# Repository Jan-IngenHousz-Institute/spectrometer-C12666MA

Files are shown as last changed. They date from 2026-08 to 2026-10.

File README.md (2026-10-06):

# C12666MA spectrometer

Hamamatsu C12666MA micro-spectrometer (340–780 nm, 256 pixels) read by a
Raspberry Pi Pico through an MCP3301 13-bit ADC, on the JII "C12666MA Board
v2". Includes a live GUI for chlorophyll fluorescence: two wavelength regions
(`incident_light`, `fluorescence`) and their ratio, the *rel. fluo. yield*,
plotted and recorded over time.

```
firmware/main.py      MicroPython firmware (copy to the Pico as main.py)
c12666ma/             Python package: driver, analysis, recorder, GUI
calibration/          pixel -> wavelength calibration and its source data
tools/hw_check.py     speed / reliability / noise check of a connected board
tests/                unit tests (no hardware needed)
notebooks/            the original measurement notebooks (K. Tolsma, 2026)
hardware/kicad/       PCB v2, two variants: Pico on the back / on the front
legacy/arduino/       earlier Arduino Uno sketches, incl. the MCP3301 bench test
```

## Quick start

```
pip install -r requirements.txt
python -m c12666ma            # the GUI
```

1. **Connect**, then **Start**. "As fast as possible" streams one spectrum per
   integration time (about 190 spectra/s at the 5.2 ms minimum). Otherwise
   set a period; the minimum is averages × integration time.
2. Cover the sensor or switch the light off and press **Take dark**. The
   yield needs a dark spectrum taken with the same gain, integration time and
   averages, and the GUI tells you when the current one no longer matches.
3. Drag the blue (`incident_light`) and red (`fluorescence`) regions, or type
   their limits.
4. Select **3D spectrum history** to view the most recent spectra as a surface
   over wavelength, time and counts. The view keeps up to 5000 spectra in
   memory, can show the latest 2–500, and updates while it is open.
5. **Start recording** writes one CSV per measurement.

### Rel. fluo. yield

`fluorescence / incident_light`, where each term is the sum of
dark-subtracted counts over its region. A region "has signal" when that sum
is more than *k* × its noise (k = 5 by default; the noise comes from the dark
frames).

| incident_light | fluorescence | result |
|---|---|---|
| signal | any | fluorescence / incident_light |
| no signal | signal | empty + warning *fluorescence without incident light* |
| no signal | no signal | 0 |

Frames with a pixel at saturation in either region are flagged (orange in
the plot, `;saturated` in the file). The saturation level is about 3100
counts at high gain and about 1950 at low gain; both can be adjusted in the
GUI.

### Recording format

Open a recording with `pandas.read_csv(path, comment="#")`. The header lines
(`# ...`) hold the settings, regions and calibration. The `kind` column
separates the row types:

- `wavelength_nm`: the wavelength of every pixel column `px0..px255`
- `dark` / `dark_std`: the dark reference (written whenever one is taken)
- `spectrum`: one row per spectrum, with the timestamp (start of
  integration), `t_s`, sequence number, settings, optionally
  `incident_light`, `fluorescence`, `rel_fluo_yield`, `yield_status`, and the
  raw counts (not dark-subtracted).

### Scripting

```python
from c12666ma import Spectrometer

with Spectrometer.open() as spec:          # finds the Pico automatically
    spec.set_integration_us(20_000)
    frame = spec.read_frame()              # frame.counts: 256 values
    spec.start_stream(period_us=0)
    frame = spec.frames.get()              # frames keep arriving until stop_stream()
    spec.stop_stream()
```

## Firmware

Copy `firmware/main.py` to the Pico as `main.py`, with Thonny or with
`mpremote cp firmware/main.py :main.py`. The serial protocol is documented
at the top of the file. Commands are text lines (`set_integration,20000`,
`spec,raw`, ...), and the v1 commands still work. Settings stay in RAM until
you send `save`.

The sensor clock (200 kHz), the start pulses and the ADC conversions are
generated by the Pico's PIO state machines, and DMA moves the samples to RAM.
The readout therefore doesn't depend on Python timing. Per the datasheet,
the integration time is the interval between start pulses, so it is exactly
N clocks for every pixel. Readout overlaps the next integration, so
streaming has no dead time.

Measured on the board in October 2026 (`python tools/hw_check.py`, 60 s
run):

| | |
|---|---|
| frame rate at the 5.175 ms minimum integration | 193.2 spectra/s, period exact to 1 µs |
| dropped frames / checksum errors / ADC framing errors | 0 / 0 / 0 (11 593 frames) |
| device CPU load at that rate | 48 % |
| dark noise | ~11 counts rms per pixel (old firmware: same median, but outliers up to 350) |

The noise floor (~11 mV rms) is set by the analog front end, not the sensor
(datasheet readout noise 0.5 mV).

## Wavelength calibration

There is no Hamamatsu inspection sheet for this unit, so
`calibration/fit_wavelength.py` fits a quadratic from two sources. The first
is four LED spectra measured with both this sensor and a reference
spectrometer (`calibration/LR1B/`). The second is the chlorophyll
fluorescence peaks (685 / ~737 nm) in 13 leaf recordings, which anchor the
red end beyond the last LED:

    nm = 345.98 + 2.3235·p − 0.0017379·p²     (p = pixel 0..255)

The RMS residual is 2.3 nm. Treat it as about ±3 nm between 470 and 745 nm,
and less certain outside that range. The coefficients are also stored on the
device (`get_wl_coeffs`), and the GUI uses them from there. Pixel → λ is
unchanged from the original firmware, so old data can use the same formula.

## Hardware notes (board v2)

- MCP3301 DOUT (5 V logic) is wired straight to GP16. The RP2040 is not 5 V
  tolerant. For the next revision, add a divider or a 3.3 V buffer; a
  ~2.2 kΩ series resistor is the quick fix.
- The video output reaches the ADC through 5 kΩ with no buffer amplifier (the
  datasheet recommends a CMOS op-amp buffer). This limits the ADC clock and
  probably adds noise.
- GP15 (the LED / excitation light) is not routed on the PCB and has to be
  wired separately.
- The schematic uses JII library symbols ("Library JII") that are embedded
  in the files but not included as a library.

## Development

```
python -m pytest                       # unit tests
python tools/hw_check.py               # with a board connected
python calibration/fit_wavelength.py   # re-fit the calibration
```

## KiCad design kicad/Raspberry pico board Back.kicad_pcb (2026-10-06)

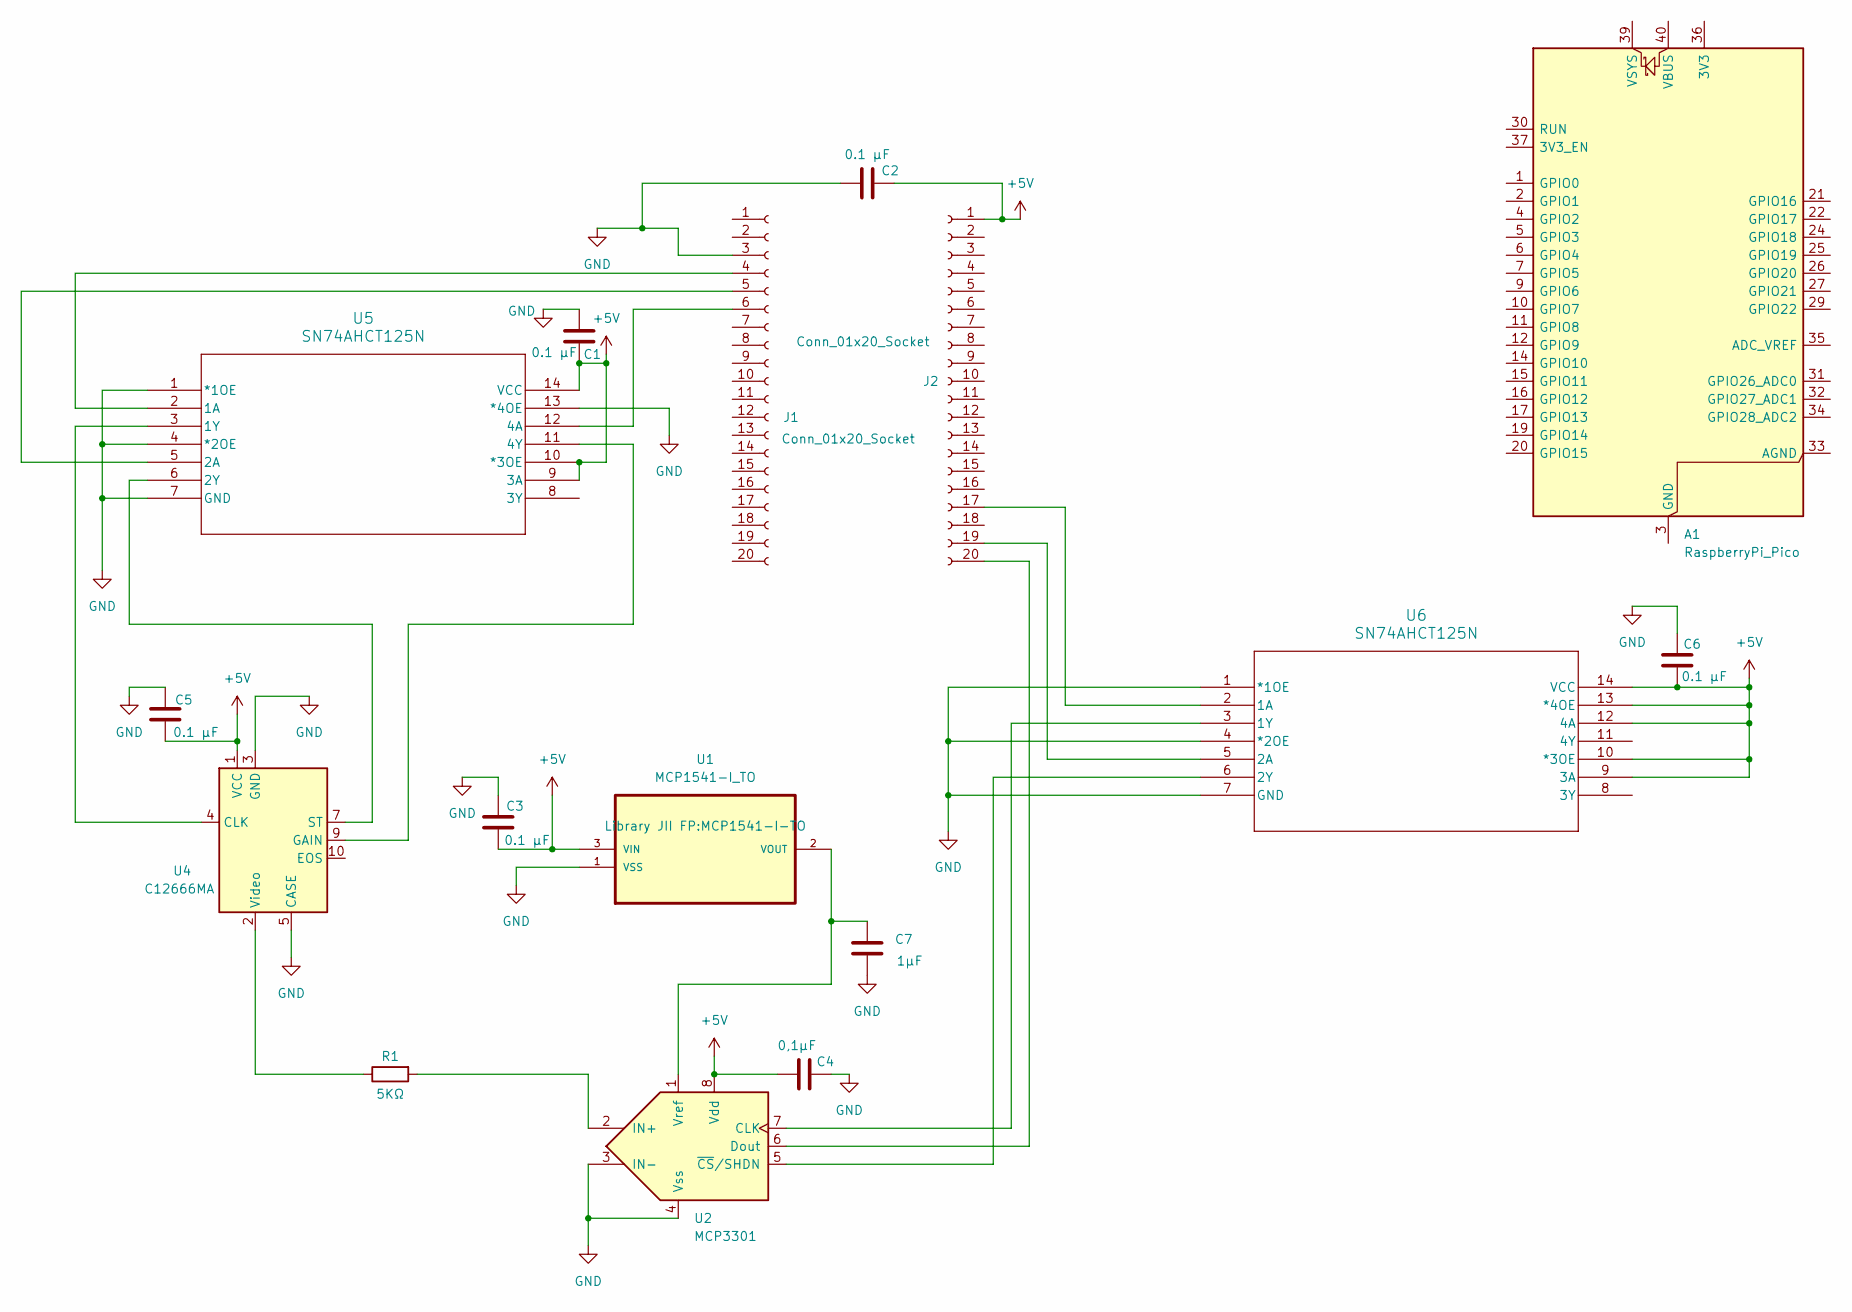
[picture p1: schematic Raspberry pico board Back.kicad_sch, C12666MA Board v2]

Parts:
A1: RaspberryPi_Pico; RaspberryPi_Pico_Common_Unspecified
C1, C2, C3, C5, C6: 0.1 μF; C_0805_2012Metric_Pad1.18x1.45mm_HandSolder
C4: 0,1μF; C_0805_2012Metric_Pad1.18x1.45mm_HandSolder
C7: 1μF; C_0805_2012Metric_Pad1.18x1.45mm_HandSolder
J1, J2: Conn_01x20_Socket; PinHeader_1x20_P2.54mm_Vertical
R1: 5KΩ; R_0805_2012Metric_Pad1.20x1.40mm_HandSolder
U1: MCP1541-I_TO; MCP1541-I-TO; MPN MCP1541-I/TO
U2: MCP3301; MCP3301_BI_P
U4: C12666MA; Hamamatsu_C12880
U5, U6: SN74AHCT125N

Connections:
+5V: C1.2, C2.2, C3.2, C4.1, C5.2, C6.2, J2.1, U1.3 (VIN), U2.8 (Vdd), U4.1 (VCC), U5.9 (3A), U5.10 (*3OE), U5.14 (VCC), U6.9 (3A), U6.10 (*3OE), U6.12 (4A), U6.13 (*4OE), U6.14 (VCC)
GND: C1.1, C2.1, C3.1, C4.2, C5.1, C6.1, C7.2, J1.3, U1.1 (VSS), U2.3 (IN-), U2.4 (Vss), U4.3 (GND), U4.5 (CASE), U5.1 (*1OE), U5.4 (*2OE), U5.7 (GND), U5.13 (*4OE), U6.1 (*1OE), U6.4 (*2OE), U6.7 (GND)
unnamed: A1.3 (GND), A1.8 (GND), A1.13 (GND), A1.18 (GND), A1.23 (GND), A1.28 (GND), A1.38 (GND)
unnamed: J1.4, U5.2 (1A)
unnamed: J1.5, U5.5 (2A)
unnamed: J1.6, U5.12 (4A)
unnamed: J2.17, U6.2 (1A)
unnamed: J2.19, U6.5 (2A)
unnamed: J2.20, U2.6 (Dout)
unnamed: C7.1, U1.2 (VOUT), U2.1 (Vref)
unnamed: U2.7 (CLK), U6.3 (1Y)
unnamed: R1.2, U2.2 (IN+)
unnamed: U2.5 (~CS/SHDN), U6.6 (2Y)
unnamed: U4.4 (CLK), U5.3 (1Y)
unnamed: U4.9 (GAIN), U5.11 (4Y)
unnamed: U4.7 (ST), U5.6 (2Y)
unnamed: R1.1, U4.2 (Video)

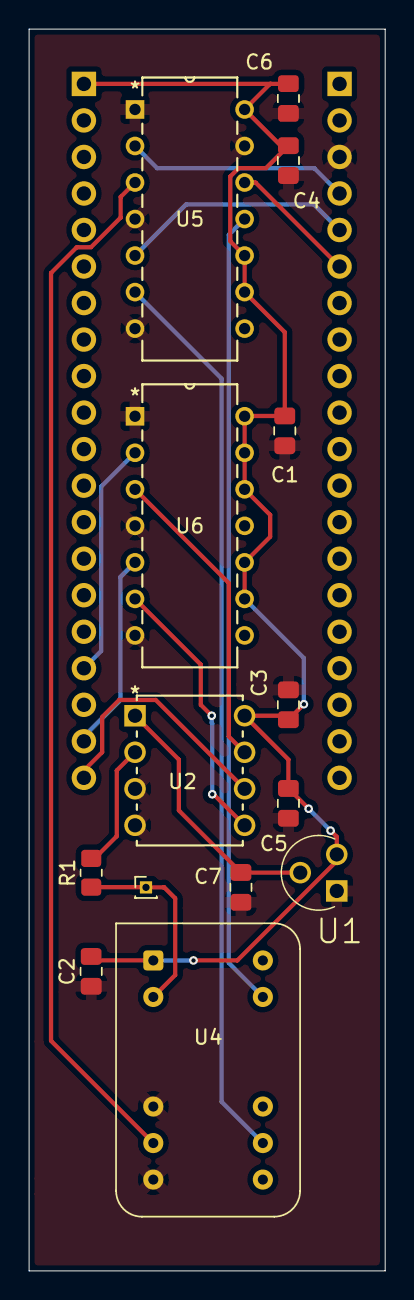
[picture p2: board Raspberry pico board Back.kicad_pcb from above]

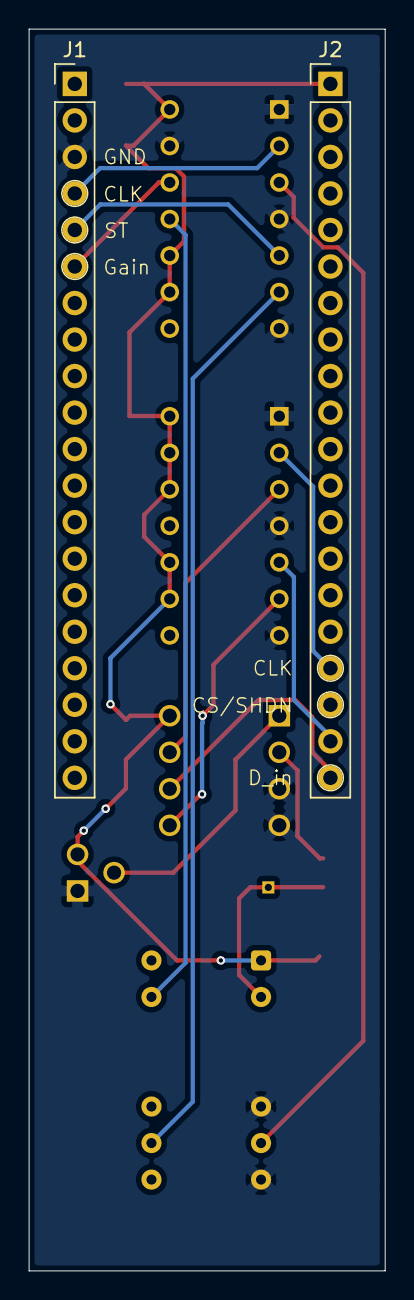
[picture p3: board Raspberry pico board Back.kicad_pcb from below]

Board: 2 copper layers, 24.8 x 86.4 mm, 15 parts (2 on the bottom side), 16 nets.

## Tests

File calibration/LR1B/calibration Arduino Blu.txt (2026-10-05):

296.156 13.772
296.345 82.772
296.534 21.772
296.723 29.772
296.912 33.772
297.101 27.772
297.290 11.772
297.479 13.772
297.668 39.771
297.858 -14.229
298.047 65.771
298.236 62.771
298.425 120.771
298.614 54.771
298.803 90.771
298.992 62.771
299.181 47.771
299.370 36.770
299.559 18.770
299.748 -8.230
299.937 29.770
300.126 62.770
300.315 9.770
300.504 35.770
300.693 66.770
300.882 41.769
301.071 -14.231
301.260 29.769
301.449 45.769
301.638 58.769
301.827 -9.231
302.016 43.769
302.205 81.769
302.395 63.768
302.584 48.768
302.773 17.768
302.962 66.768
303.151 75.768
303.340 56.768
303.529 31.768
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

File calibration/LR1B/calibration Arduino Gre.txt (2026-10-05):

296.156 6.886
296.345 34.886
296.534 39.886
296.723 76.886
296.912 33.886
297.101 -80.114
297.290 -17.114
297.479 49.886
297.668 31.886
297.858 29.886
298.047 34.886
298.236 9.886
298.425 49.885
298.614 65.885
298.803 85.885
298.992 39.885
299.181 -15.115
299.370 54.885
299.559 77.885
299.748 51.885
299.937 42.885
300.126 74.885
300.315 44.885
300.504 37.885
300.693 43.885
300.882 24.885
301.071 -12.115
301.260 45.885
301.449 85.885
301.638 60.884
301.827 41.884
302.016 71.884
302.205 62.884
302.395 41.884
302.584 -11.116
302.773 42.884
302.962 58.884
303.151 12.884
303.340 54.884
303.529 51.884
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

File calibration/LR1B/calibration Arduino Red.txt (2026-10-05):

296.156 42.986
296.345 81.986
296.534 42.986
296.723 30.986
296.912 2.986
297.101 35.986
297.290 -2.014
297.479 22.986
297.668 51.986
297.858 92.986
298.047 -22.014
298.236 -22.014
298.425 -5.014
298.614 59.986
298.803 -7.014
298.992 5.986
299.181 -65.014
299.370 -37.014
299.559 15.986
299.748 11.986
299.937 14.986
300.126 -3.014
300.315 59.986
300.504 23.986
300.693 5.986
300.882 41.986
301.071 43.986
301.260 -19.014
301.449 6.986
301.638 56.986
301.827 43.986
302.016 16.986
302.205 -21.014
302.395 -1.014
302.584 13.986
302.773 -3.014
302.962 45.986
303.151 22.985
303.340 -0.015
303.529 22.985
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

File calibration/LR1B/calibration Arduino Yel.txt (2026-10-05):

296.156 -18.171
296.345 -27.171
296.534 6.829
296.723 50.829
296.912 20.829
297.101 27.829
297.290 51.829
297.479 25.829
297.668 74.829
297.858 68.829
298.047 65.828
298.236 49.828
298.425 34.828
298.614 36.828
298.803 79.828
298.992 33.828
299.181 23.828
299.370 15.828
299.559 18.828
299.748 42.828
299.937 -2.172
300.126 -36.173
300.315 15.827
300.504 13.827
300.693 88.827
300.882 12.827
301.071 57.827
301.260 71.827
301.449 35.827
301.638 18.827
301.827 3.827
302.016 45.827
302.205 34.826
302.395 83.826
302.584 -2.174
302.773 -8.174
302.962 -5.174
303.151 35.826
303.340 52.826
303.529 43.826
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

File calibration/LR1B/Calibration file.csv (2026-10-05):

timestamp | pixel0 | 1 | 2 | 3 | 4 | 5 | 6 | 7 | 8 | 9 | 10 | 11 | 12 | 13 | 14 | 15 | 16 | 17 | 18 | 19 | 20 | 21 | 22 | 23 | 24 | 25 | 26 | 27 | 28 | 29 | 30 | 31 | 32 | 33 | 34 | 35 | 36 | 37 | 38 | 39 | 40 | 41 | 42 | 43 | 44 | 45 | 46 | 47 | 48 | 49 | 50 | 51 | 52 | 53 | 54 | 55 | 56 | 57 | 58
7-8-2026 10:11 | 17 | 31 | 32 | 24 | 22 | 37 | 30 | 6 | 17 | 28 | 24 | 22 | 20 | 23 | 23 | 24 | 17 | 20 | 22 | 28 | 20 | 20 | 29 | 26 | 24 | 28 | 34 | 17 | 24 | 26 | 20 | 25 | 18 | 26 | 25 | 28 | 23 | 33 | 41 | 53 | 62 | 77 | 99 | 108 | 148 | 168 | 222 | 294 | 372 | 474 | 610 | 765 | 918 | 1056 | 1154 | 1140 | 1070 | 961 | 853
7-8-2026 10:11 | 24 | 27 | 27 | 23 | 23 | 33 | 34 | 27 | 22 | 31 | 39 | 22 | 23 | 36 | 29 | 26 | 31 | 34 | 22 | 32 | 28 | 26 | 45 | 36 | 35 | 32 | 29 | 26 | 27 | 31 | 27 | 26 | 23 | 27 | 35 | 37 | 33 | 43 | 49 | 49 | 67 | 92 | 96 | 125 | 148 | 178 | 226 | 292 | 382 | 476 | 621 | 775 | 924 | 1068 | 1149 | 1153 | 1072 | 972 | 856
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

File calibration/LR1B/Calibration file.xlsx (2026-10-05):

timestamp | pixel0 | 1 | 2 | 3 | 4 | 5 | 6 | 7 | 8 | 9 | 10 | 11 | 12 | 13 | 14 | 15 | 16 | 17 | 18 | 19 | 20 | 21 | 22 | 23 | 24 | 25 | 26 | 27 | 28 | 29 | 30 | 31 | 32 | 33 | 34 | 35 | 36 | 37 | 38 | 39 | 40 | 41 | 42 | 43 | 44 | 45 | 46 | 47 | 48 | 49 | 50 | 51 | 52 | 53 | 54 | 55 | 56 | 57 | 58
2026-08-07 10:11 | 17 | 31 | 32 | 24 | 22 | 37 | 30 | 6 | 17 | 28 | 24 | 22 | 20 | 23 | 23 | 24 | 17 | 20 | 22 | 28 | 20 | 20 | 29 | 26 | 24 | 28 | 34 | 17 | 24 | 26 | 20 | 25 | 18 | 26 | 25 | 28 | 23 | 33 | 41 | 53 | 62 | 77 | 99 | 108 | 148 | 168 | 222 | 294 | 372 | 474 | 610 | 765 | 918 | 1056 | 1154 | 1140 | 1070 | 961 | 853
2026-08-07 10:11 | 24 | 27 | 27 | 23 | 23 | 33 | 34 | 27 | 22 | 31 | 39 | 22 | 23 | 36 | 29 | 26 | 31 | 34 | 22 | 32 | 28 | 26 | 45 | 36 | 35 | 32 | 29 | 26 | 27 | 31 | 27 | 26 | 23 | 27 | 35 | 37 | 33 | 43 | 49 | 49 | 67 | 92 | 96 | 125 | 148 | 178 | 226 | 292 | 382 | 476 | 621 | 775 | 924 | 1068 | 1149 | 1153 | 1072 | 972 | 856
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

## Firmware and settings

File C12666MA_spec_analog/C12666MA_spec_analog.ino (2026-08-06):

/*
 * ============================================================================
 *  C12666MA_spectrometer.ino
 *  Hamamatsu C12666MA micro-spectrometer reader for the Arduino Uno (ATmega328P)
 * ============================================================================
 *
 *  Reads all 256 pixels of the sensor and sends them to a host PC over USB
 *  serial, using simple comma-separated text commands. Beginner-friendly:
 *  plain functions and global variables, one file, lots of comments.
 *
 *  --- WIRING (Uno is 5V, so no level shifters or op-amps are required) -------
 *     Sensor CLK   -> Uno A2   (digital output)
 *     Sensor ST    -> Uno A1   (digital output)
 *     Sensor VIDEO -> Uno A3   (ANALOG input, read with analogRead)
 *     Sensor Gain  -> Uno A0   (digital output - see GAIN PIN note below)
 *     Sensor +Vs   -> Uno 5V
 *     Sensor GND   -> Uno GND
 *     Sensor EOS   -> not used by this sketch, can be left unconnected
 *     Sensor Case  -> Uno GND (recommended, reduces noise pickup)
 *
 *  --- GAIN PIN NOTE -----------------------------------------------------------
 *     Unlike the C12880MA, the C12666MA has a Gain pin (sensor pin 9) instead
 *     of a Trigger pin. Per the Hamamatsu datasheet:
 *       - Low gain:  pin left open, or driven/pulled to Vdd (5V)
 *       - High gain: pin driven to GND (<0.4V)
 *     The sensor already has a 10 kOhm internal pull-up to Vdd on this pin, so
 *     do NOT add an external pull-up or pull-down resistor - just wire it
 *     straight to A0. This sketch drives A0 as an output so gain is set
 *     explicitly in software rather than left floating.
 *
 *  --- INTEGRATION TIME NOTE ----------------------------------------------------
 *     The C12666MA's datasheet-specified minimum integration time is much
 *     longer than the C12880MA's (roughly 1.28 ms vs ~11 us). This sketch
 *     defaults to and enforces a 1280 us floor - see MIN_INTEGRATION_US below.
 *
 *  --- ACQUISITION PROTOCOL (verified against groupgets/c12666ma) -------------
 *     The C12666MA's readout sequence is NOT the same shape as the C12880MA's
 *     and differs in two important ways:
 *       1. VIDEO only updates once every 4 CLK pulses (the datasheet states
 *          "video output is 1/4 of the clock pulse frequency"), so each
 *          pixel needs a 4-clock group, with the valid sample taken on the
 *          first clock's falling edge.
 *       2. ST idles HIGH and is only pulsed briefly LOW - once to mark the
 *          start of integration, once to mark the end - rather than staying
 *          low for the whole pixel readout. The datasheet notes: "The clock
 *          pulse should be set from high to low just once when the start
 *          pulse is low. The internal shift register starts operating at
 *          this timing," i.e. that single edge is what actually triggers
 *          the sensor, so it has to be timed precisely.
 *     This sketch's acquireOnePass() follows that six-step sequence (leading
 *     clocks, start pulse, integration, stop pulse, 4-clocks-per-pixel read,
 *     trailing clocks), matching the reference sketch at:
 *       https://github.com/groupgets/c12666ma
 *       https://github.com/tricorderproject/arducordermini
 *
 *  --- HOW TO USE -------------------------------------------------------------
 *     1. Upload with the Arduino IDE (board: "Arduino Uno").
 *     2. Open Serial Monitor at 115200 baud, line ending = "Carriage Return".
 *     3. Type commands (see the table in handleCommand() below), e.g.:
 *          hello
 *          set_integration,2000
 *          set_gain,1      (0 = low gain, 1 = high gain)
 *          dark            (capture a dark reference with the sensor covered)
 *          spec            (dark-subtracted spectrum, 256 numbers)
 *          spec,raw        (raw spectrum, 256 numbers)
 *
 *  Adapted from a C12880MA sketch ported from the GroupGets C12880MA Arduino
 *  example (https://github.com/groupgets/c12666ma) for the C12666MA sensor.
 *  Timing constants that are sensor-specific have been called out above -
 *  please verify them against your hardware before trusting the output.
 * ============================================================================
 */

#include <EEPROM.h>

// ============================================================================
//  1. PINS & CONSTANTS
// ============================================================================

// Pin assignments (match the GroupGets breakout layout).
const uint8_t SPEC_CLK   = A2;   // clock output to the sensor
const uint8_t SPEC_ST    = A1;   // start pulse output to the sensor
const uint8_t SPEC_VIDEO = A3;   // analog video input from the sensor
const uint8_t SPEC_GAIN  = A0;   // gain select output to the sensor (pin 9)
const uint8_t LED_PIN    = 2;    // external status LED (pin 0/1 are used by
                                  // Serial - don't repurpose those)

// Gain pin logic levels (see GAIN PIN note above).
const uint8_t GAIN_LOW  = HIGH;  // low gain:  pin at/near Vdd
const uint8_t GAIN_HIGH = LOW;   // high gain: pin at/near GND

// The sensor has 256 pixels (spectral channels).
const int SPEC_CHANNELS = 256;

// Half-period of each clock pulse, in microseconds. 1 us gives a clean,
// slow clock that the sensor is happy with. Bigger = slower and safer.
// The C12666MA datasheet allows a clock frequency of 1 kHz to 800 kHz
// (f(CLK)), so this slow default clock is comfortably within range.
const int CLK_DELAY_US = 1;

// Datasheet-specified minimum integration time for the C12666MA is about
// 1.28 ms. We enforce this floor in set_integration() so a mistaken
// set_integration,0 command can't silently produce underexposed frames.
const unsigned long MIN_INTEGRATION_US = 5000UL;

// Averaging is capped so the uint16 accumulator (in g_data) cannot overflow:
// 63 * 1023 = 64449, which is below 65535. This also keeps us inside the
// Uno's 2 KB of RAM (a 32-bit accumulator array would not fit next to g_dark).
const uint8_t MAX_AVG = 63;

// ============================================================================
//  2. CONFIGURATION STORED IN EEPROM
// ============================================================================
// The Uno has no filesystem, so settings that must survive a power cycle are
// kept in EEPROM. A "magic" byte lets us detect a blank chip and load defaults.

const uint8_t CONFIG_MAGIC = 0x66;   // bumped from the C12880MA version (0x43)
                                      // since the struct below gained a field -
                                      // change this again if you change the struct

struct Config {
  uint8_t       magic;             // must equal CONFIG_MAGIC if valid
  char          name[16];          // human-friendly device name
  unsigned long integration_us;    // extra exposure time (microseconds)
  uint8_t       n_avg;             // number of frames to average (1..MAX_AVG)
  float         wl_coeffs[6];      // wavelength polynomial A0..A5 (used host-side)
  uint8_t       high_gain;         // 0 = low gain, 1 = high gain
};

Config g_cfg;   // the live copy of our settings

// ============================================================================
//  3. FRAME BUFFERS  (the biggest users of RAM)
// ============================================================================

uint16_t g_data[SPEC_CHANNELS];   // latest frame; also used as the average sum
uint16_t g_dark[SPEC_CHANNELS];   // dark reference frame
bool     g_have_dark = false;     // true once a dark frame has been captured
bool     g_led_on = false;        // current LED state (not persisted in EEPROM -
                                   // always starts off after a reboot)

// ============================================================================
//  4. SERIAL COMMAND BUFFER
// ============================================================================
// We read characters into a fixed char array (not a String) to avoid the
// memory-fragmentation problems that String can cause on small AVR chips.

char    g_cmd[40];
uint8_t g_cmd_len = 0;

// ---------------------------------------------------------------------------
//  Soft reset: jumping to address 0 restarts the sketch. (Simple, not a full
//  hardware reset, but fine for the "reboot" command.)
// ---------------------------------------------------------------------------
void (*resetBoard)(void) = 0;

// ============================================================================
//  EEPROM helpers
// ============================================================================

void saveConfig() {
  EEPROM.put(0, g_cfg);
}

void loadConfig() {
  EEPROM.get(0, g_cfg);
  if (g_cfg.magic != CONFIG_MAGIC) {
    // Blank or outdated EEPROM: fill in sensible defaults and store them.
    g_cfg.magic = CONFIG_MAGIC;
    strcpy(g_cfg.name, "C12666MA");
    g_cfg.integration_us = MIN_INTEGRATION_US;   // datasheet minimum, not 0
    g_cfg.n_avg = 1;               // no averaging by default
    for (int i = 0; i < 6; i++) g_cfg.wl_coeffs[i] = 0.0;
    g_cfg.high_gain = 0;           // low gain by default
    saveConfig();
  }
  // Make sure a corrupted value can never break averaging or integration.
  if (g_cfg.n_avg < 1)       g_cfg.n_avg = 1;
  if (g_cfg.n_avg > MAX_AVG) g_cfg.n_avg = MAX_AVG;
  if (g_cfg.integration_us < MIN_INTEGRATION_US) g_cfg.integration_us = MIN_INTEGRATION_US;
}

// ============================================================================
//  5. ACQUISITION
// ============================================================================

// One low/high clock pulse on SPEC_CLK (order matches the reference sketch;
// what matters for a free-running train is that transitions are evenly
// spaced, so this is equivalent to a high/low pulse for anything except the
// edge-critical start/stop pulses handled separately in pulseStartStop()).
void pulseClock() {
  digitalWrite(SPEC_CLK, LOW);
  delayMicroseconds(CLK_DELAY_US);
  digitalWrite(SPEC_CLK, HIGH);
  delayMicroseconds(CLK_DELAY_US);
}

// Push the current gain setting out to the sensor's Gain pin.
void applyGain() {
  digitalWrite(SPEC_GAIN, g_cfg.high_gain ? GAIN_HIGH : GAIN_LOW);
}

// A brief ST HIGH->LOW->HIGH pulse, timed to CLK edges. Called once to mark
// the start of integration and again to mark the end - the sequence is
// identical both times (see ACQUISITION PROTOCOL note up top). The single
// CLK falling edge that happens while ST is LOW is what actually triggers
// the sensor's internal shift register, per the datasheet.
void pulseStartStop() {
  digitalWrite(SPEC_CLK, LOW);
  delayMicroseconds(CLK_DELAY_US);
  digitalWrite(SPEC_CLK, HIGH);
  digitalWrite(SPEC_ST, LOW);
  delayMicroseconds(CLK_DELAY_US);

  digitalWrite(SPEC_CLK, LOW);
  delayMicroseconds(CLK_DELAY_US);
  digitalWrite(SPEC_CLK, HIGH);
  digitalWrite(SPEC_ST, HIGH);
  delayMicroseconds(CLK_DELAY_US);
}

// Run the sensor once and ADD the 256 readings into g_data (so it can be
// called several times in a row to average). Six-step sequence verified
// against the groupgets/c12666ma reference sketch - see ACQUISITION
// PROTOCOL note up top for why this differs from a typical C12880MA sketch.
void acquireOnePass() {
  // -- Step 1: one full frame's worth of leading clocks, ST idling HIGH. --
  for (int i = 0; i < SPEC_CHANNELS; i++) pulseClock();

  // -- Step 2: start pulse - marks the beginning of integration. --
  pulseStartStop();

  // -- Step 3: integration window. ST stays HIGH; CLK keeps running so the
  //    sensor's internal clocking stays alive, in groups of 2 pulseClock()
  //    calls (~1 clock cycle each). We time this against a real elapsed-
  //    microsecond count via micros(), NOT by estimating clock counts -
  //    digitalWrite() call overhead on the Uno is several microseconds per
  //    call, which dwarfs CLK_DELAY_US and made a clock-counting estimate
  //    badly inaccurate. This loop instead keeps pulsing until the
  //    requested integration_us has actually elapsed. --
  unsigned long intStart = micros();
  while ((unsigned long)(micros() - intStart) < g_cfg.integration_us) {
    pulseClock();
    pulseClock();
  }

  // -- Step 4: stop pulse - marks the end of integration; pixel shift-out
  //    begins right after. --
  pulseStartStop();

  // -- Step 5: read the 256 real pixels. Each pixel gets a 4-clock group;
  //    VIDEO is valid on the first clock's falling edge, so that's where we
  //    sample. The remaining 3 clocks just shift to the next pixel. --
  for (int i = 0; i < SPEC_CHANNELS; i++) {
    digitalWrite(SPEC_CLK, LOW);
    delayMicroseconds(CLK_DELAY_US);
    digitalWrite(SPEC_CLK, HIGH);
    delayMicroseconds(CLK_DELAY_US);
    digitalWrite(SPEC_CLK, LOW);
    // Settling delay before sampling. If a buffer op-amp is in the signal
    // path, this needs to cover its worst-case slew time, not just RC
    // settling: e.g. the OPA347's slew rate is only ~0.17 V/us typical, so
    // a full-scale step (a few volts, as can happen pixel-to-pixel at a
    // sharp spectral edge) can take ~15-20us to fully settle. Without a
    // buffer, a much shorter delay (a few us) is enough for the sensor's
    // own ~150 ohm output impedance to settle. Tune this to your actual
    // signal path; too short truncates real amplitude (readings looking
    // "compressed" versus the scope), too long just slows readout.
    delayMicroseconds(20);
    g_data[i] += analogRead(SPEC_VIDEO);   // valid right after this falling edge
    digitalWrite(SPEC_CLK, HIGH);
    delayMicroseconds(CLK_DELAY_US);
    pulseClock();
    pulseClock();
  }

  // -- Step 6: one full frame's worth of trailing clocks, leaves the sensor
  //    ready for the next acquisition. --
  for (int i = 0; i < SPEC_CHANNELS; i++) pulseClock();
}

// Read a full spectrum into g_data, averaging g_cfg.n_avg passes.
void readSpectrometer() {
  for (int i = 0; i < SPEC_CHANNELS; i++) g_data[i] = 0;   // clear accumulator

  for (uint8_t p = 0; p < g_cfg.n_avg; p++) acquireOnePass();

  if (g_cfg.n_avg > 1) {
    for (int i = 0; i < SPEC_CHANNELS; i++) g_data[i] /= g_cfg.n_avg;
  }
}

// Capture the current reading as the dark reference.
void captureDark() {
  readSpectrometer();
  for (int i = 0; i < SPEC_CHANNELS; i++) g_dark[i] = g_data[i];
  g_have_dark = true;
}

// ============================================================================
//  6. OUTPUT HELPERS
// ============================================================================

// Print the spectrum as one line of comma-separated numbers, ending in '\r'.
// raw == true  -> raw counts
// raw == false -> dark-subtracted counts (clamped at 0), if a dark frame exists
void printSpectrum(bool raw) {
  for (int i = 0; i < SPEC_CHANNELS; i++) {
    int value;
    if (raw || !g_have_dark) {
      value = g_data[i];
    } else {
      value = (int)g_data[i] - (int)g_dark[i];
      if (value < 0) value = 0;
    }
    Serial.print(value);
    if (i < SPEC_CHANNELS - 1) Serial.print(',');
  }
  Serial.print('\r');
}

// Print the six wavelength coefficients as a JSON array.
void printWlCoeffs() {
  Serial.print(F("{\"wl_coeffs\":["));
  for (int i = 0; i < 6; i++) {
    Serial.print(g_cfg.wl_coeffs[i], 8);   // 8 decimal places
    if (i < 5) Serial.print(',');
  }
  Serial.print(F("]}\r"));
}

// ============================================================================
//  7. COMMAND HANDLING
// ============================================================================
//
//  Supported commands (each line ends with Carriage Return, '\r'):
//    hello                     -> "C12666MA,v1.0"        (auto-discovery)
//    idn                       -> "C12666MA_UNO_v1.0"
//    spec                      -> dark-subtracted spectrum (256 numbers)
//    spec,raw                  -> raw spectrum (256 numbers)
//    set_integration,<us>      -> {"integration_us":<n>}  (floored at 1280)
//    get_integration           -> <n>
//    set_gain,<0|1>            -> {"high_gain":<0|1>}     (0=low, 1=high)
//    get_gain                  -> <0|1>
//    set_led,<0|1>             -> {"led":<0|1>}          (0=off, 1=on)
//    get_led                   -> <0|1>
//    dark                      -> {"dark":"ok"}          (capture dark frame)
//    clear_dark                -> {"dark":"cleared"}
//    set_avg,<n>               -> {"n_avg":<n>}          (1..63)
//    get_avg                   -> <n>
//    set_wl_coeff,<i>,<value>  -> {"wl_coeffs":[...]}    (i = 0..5)
//    get_wl_coeffs             -> {"wl_coeffs":[...]}
//    set_name,<text>           -> {"device_name":"..."}
//    get_name                  -> <name>
//    reboot                    -> soft reset
//
void handleCommand(char *cmd) {
  // strtok() splits the command on commas. The first token is the command name.
  char *tok = strtok(cmd, ",");
  if (tok == NULL) return;

  if (strcmp(tok, "hello") == 0) {
    Serial.print(F("C12666MA,v1.0\r\n"));

  } else if (strcmp(tok, "idn") == 0) {
    Serial.print(F("C12666MA_UNO_v1.0\r\n"));

  } else if (strcmp(tok, "spec") == 0) {
    char *arg = strtok(NULL, ",");                 // optional "raw"
    bool raw = (arg != NULL && strcmp(arg, "raw") == 0);
    readSpectrometer();
    printSpectrum(raw);
    Serial.print("\r\n");

  } else if (strcmp(tok, "set_integration") == 0) {
    char *arg = strtok(NULL, ",");
    if (arg != NULL) {
      unsigned long requested = atol(arg);
      g_cfg.integration_us = (requested < MIN_INTEGRATION_US) ? MIN_INTEGRATION_US : requested;
      saveConfig();
    }
    Serial.print(F("{\"integration_us\":"));
    Serial.print(g_cfg.integration_us);
    Serial.print(F("}\r\n"));

  } else if (strcmp(tok, "get_integration") == 0) {
    Serial.print(g_cfg.integration_us);
    Serial.print('\r');
    Serial.print("\n");

  } else if (strcmp(tok, "set_gain") == 0) {
    char *arg = strtok(NULL, ",");
    if (arg != NULL) {
      g_cfg.high_gain = (atoi(arg) != 0) ? 1 : 0;
      applyGain();
      saveConfig();
    }
    Serial.print(F("{\"high_gain\":"));
    Serial.print(g_cfg.high_gain);
    Serial.print(F("}\r\n"));

  } else if (strcmp(tok, "get_gain") == 0) {
    Serial.print(g_cfg.high_gain);
    Serial.print(F("\r\n"));

  } else if (strcmp(tok, "set_led") == 0) {
    char *arg = strtok(NULL, ",");
    if (arg != NULL) {
      g_led_on = (atoi(arg) != 0);
      digitalWrite(LED_PIN, g_led_on ? HIGH : LOW);
    }
    Serial.print(F("{\"led\":"));
    Serial.print(g_led_on);
    Serial.print(F("}\r\n"));

  } else if (strcmp(tok, "get_led") == 0) {
    Serial.print(g_led_on);
    Serial.print(F("\r\n"));

  } else if (strcmp(tok, "dark") == 0) {
    captureDark();
    Serial.print(F("{\"dark\":\"ok\"}\r\n"));

  } else if (strcmp(tok, "clear_dark") == 0) {
    g_have_dark = false;
    Serial.print(F("{\"dark\":\"cleared\"}\r\n"));

  } else if (strcmp(tok, "set_avg") == 0) {
    char *arg = strtok(NULL, ",");
    if (arg != NULL) {
      int n = atoi(arg);
      if (n < 1) n = 1;
      if (n > MAX_AVG) n = MAX_AVG;
      g_cfg.n_avg = (uint8_t)n;
      saveConfig();
    }
    Serial.print(F("{\"n_avg\":"));
    Serial.print(g_cfg.n_avg);
    Serial.print(F("}\r\n"));

  } else if (strcmp(tok, "get_avg") == 0) {
    Serial.print(g_cfg.n_avg);
    Serial.print(F("\r\n"));

  } else if (strcmp(tok, "set_wl_coeff") == 0) {
    char *sIndex = strtok(NULL, ",");
    char *sValue = strtok(NULL, ",");
    if (sIndex != NULL && sValue != NULL) {
      int idx = atoi(sIndex);
      if (idx >= 0 && idx < 6) {
        g_cfg.wl_coeffs[idx] = atof(sValue);       // text -> float
        saveConfig();
      }
    }
    printWlCoeffs();

  } else if (strcmp(tok, "get_wl_coeffs") == 0) {
    printWlCoeffs();

  } else if (strcmp(tok, "set_name") == 0) {
    char *arg = strtok(NULL, ",");
    if (arg != NULL) {
      strncpy(g_cfg.name, arg, sizeof(g_cfg.name) - 1);
      g_cfg.name[sizeof(g_cfg.name) - 1] = '\0';   // always null-terminate
      saveConfig();
    }
    Serial.print(F("{\"device_name\":\""));
    Serial.print(g_cfg.name);
    Serial.print(F("\"}\r\n"));

  } else if (strcmp(tok, "get_name") == 0) {
    Serial.print(g_cfg.name);
    Serial.print(F("\r\n"));

  } else if (strcmp(tok, "reboot") == 0) {
    Serial.print(F("{\"reboot\":\"ok\"}\r"));
    delay(50);            // let the reply flush out
    resetBoard();

  } else {
    Serial.print(F("{\"error\":\"unknown\"}\r\n"));
  }
}

// ============================================================================
//  8. setup() / loop()
// ============================================================================

void setup() {
  pinMode(SPEC_CLK,  OUTPUT);
  pinMode(SPEC_ST,   OUTPUT);
  pinMode(SPEC_GAIN, OUTPUT);
  pinMode(LED_PIN,   OUTPUT);
  digitalWrite(SPEC_CLK, LOW);
  digitalWrite(SPEC_ST,  HIGH);   // ST idles HIGH on the C12666MA, not LOW
  digitalWrite(LED_PIN,  LOW);    // start with the LED off
  // SPEC_VIDEO is an analog input and needs no pinMode().

  analogReference(DEFAULT);   // 5 V ADC reference (matches the VIDEO range)

  Serial.begin(115200);
  loadConfig();
  applyGain();   // drive the Gain pin to match the loaded/default setting
}

void loop() {
  // Collect characters until we see a line terminator, then run the command.
  while (Serial.available() > 0) {
    char c = Serial.read();

    if (c == '\r' || c == '\n') {
      if (g_cmd_len > 0) {
        g_cmd[g_cmd_len] = '\0';   // finish the string
        handleCommand(g_cmd);
        g_cmd_len = 0;
      }
    } else if (g_cmd_len < sizeof(g_cmd) - 1) {
      g_cmd[g_cmd_len++] = c;
    }
    // (characters beyond the buffer size are dropped on purpose)
  }
}

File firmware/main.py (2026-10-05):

# =============================================================================
#  main.py  -  Hamamatsu C12666MA spectrometer firmware
#  MicroPython for the Raspberry Pi Pico (RP2040) on the JII "C12666MA Board v2"
#  (C12666MA + MCP3301 13-bit ADC + MCP1541 4.096 V reference).
# =============================================================================
#
#  Install: copy this file to the Pico as  main.py  (Thonny: File > Save as >
#  Raspberry Pi Pico, or `mpremote cp firmware/main.py :main.py`). It starts on
#  power-up. Ctrl-C in Thonny still stops it and gives you the REPL.
#
#  --- WIRING (GPIO numbers) -----------------------------------------------------
#     GP2  sensor CLK      (via 74AHCT125 to 5 V)
#     GP3  sensor ST       (via 74AHCT125 to 5 V)
#     GP4  sensor Gain     (via 74AHCT125, 0 = high gain, 1 = low gain)
#     GP15 LED / excitation light
#     GP16 MCP3301 DOUT    (NOTE: 5 V logic straight into the Pico on board v2)
#     GP17 MCP3301 CS
#     GP18 MCP3301 CLK
#
#  --- HOW THE READOUT WORKS ------------------------------------------------------
#  All sensor timing is generated in hardware, so it does not depend on the
#  Python interpreter, garbage collection or USB interrupts:
#    PIO SM0  drives CLK and ST. One "command" word = one start-pulse period:
#             ST pulse, 1024 readout clocks (256 pixels x 4), extra clocks.
#    PIO SM1  runs one MCP3301 conversion per pixel. SM0 triggers it at the
#             datasheet "TRIG" point (the low phase just before the pixel's
#             video output ends).
#    DMA      copies every conversion into a ring buffer in RAM.
#  The CPU only queues commands, sums scans and sends them over USB.
#
#  From the datasheet (KACC1216E): the integration time IS the interval
#  between start pulses, every start pulse also starts the readout of the
#  previous integration, the start pulse must stay high >= 1030 clocks, CLK
#  duty must be 45-55 % and only one CLK falling edge may occur while ST is
#  low. The clock is crystal-derived, so the integration time is exact
#  (N clocks), identical for every pixel, and continuous streaming has no
#  dead time: at the minimum integration time (~5.2 ms at 200 kHz) it
#  delivers ~190 spectra/s.
#
#  --- SERIAL PROTOCOL ---------------------------------------------------------
#  Commands are text lines ending in "\n" or "\r". Replies are one text line
#  ending in "\n". The old (v1) command names still work.
#    hello                     -> C12666MA,v1.0      (device discovery)
#    idn                       -> C12666MA_PICO_PY_v2.0
#    status                    -> JSON with all settings and counters
#    spec / spec,raw           -> one spectrum as 256 comma-separated numbers
#                                 (spec subtracts the on-device dark frame)
#    frame                     -> one spectrum as a binary FRAME packet
#    set_integration,<us>      -> {"integration_us":<actual>}
#    set_gain,<0|1>            -> {"high_gain":<0|1>}  (1 = high gain)
#    set_avg,<n>               -> {"n_avg":<n>}        (1..16 scans summed)
#    set_led,<0|1>             -> {"led":<0|1>}
#    set_period,<us>           -> {"period_us":<n>}    (streaming; 0 = fastest)
#    set_clock,<hz>            -> {"clk_hz":<actual>}  (sensor clock)
#    get_integration / get_gain / get_avg / get_led / get_period / get_clock
#    dark / clear_dark         -> on-device dark frame used by `spec`
#    set_wl_coeff,<i>,<value>  / get_wl_coeffs   (pixel -> nm polynomial)
#    set_name,<text> / get_name
#    save                      -> write settings to flash (set_* no longer do)
#    stream[,<period_us>]      -> start streaming binary packets
#    stop                      -> stop streaming
#    reboot
#
#  While streaming, everything the device sends is a packet:
#    A5 5A | type u8 | length u16 | payload | crc32 u32
#  (little endian, crc32 over type+length+payload). type 1 = FRAME, type 2 =
#  TEXT (the reply to a command, or an event). Commands can still be sent;
#  set_led takes effect immediately, other settings restart the readout.
#  FRAME payload (544 bytes):
#    u32 seq, u64 t_start_us (device clock, start of integration),
#    u32 integration_us, u32 integration_clocks, u32 clk_hz,
#    u8 n_avg, u8 high_gain, u8 led, u8 flags, u16 n_pixels, u16 adc_errors,
#    256 x u16 pixel sums (divide by n_avg for counts)
#  flags: 1 = LED switched during the frame, 2 = first frame after a
#  (re)start, 4 = frame started late, 8 = ADC framing error.
# =============================================================================

import sys
import time
import select
import struct
import array
import micropython
import machine
import rp2
import uctypes
import binascii
from machine import Pin
from collections import deque

try:
    import ujson as json
except ImportError:
    import json

# =============================================================================
#  1. PINS & CONSTANTS
# =============================================================================

FW_ID = "C12666MA_PICO_PY_v2.0"
HELLO = "C12666MA,v1.0"        # unchanged so existing scripts still find it

PIN_CLK = 2
PIN_ST = 3
PIN_GAIN = 4
PIN_LED = 15
PIN_ADC_DOUT = 16
PIN_ADC_CS = 17
PIN_ADC_SCK = 18

GAIN_LOW_LEVEL = 1             # Gain pin at Vdd  -> low gain
GAIN_HIGH_LEVEL = 0            # Gain pin at GND  -> high gain

N_PIXELS = 256
TICKS_PER_CLK = 20             # PIO cycles per sensor clock (see programs)
CMD_FIXED_CLKS = 1027          # clocks in a command besides the extra ones
MIN_PERIOD_CLKS = 1035         # >= 1030 clocks between start pulses + margin
FLUSH_CLKS = 1100              # clocks with ST high to finish a cut-off scan
CLK_DEFAULT_HZ = 200_000       # MCP3301 SCK = 5 x this (1 MHz)
CLK_MIN_HZ = 20_000
CLK_MAX_HZ = 300_000           # SCK 1.5 MHz, MCP3301 max is 1.7 MHz at 5 V
MAX_INTEGRATION_US = 10_000_000
MAX_AVG = 16                   # 16 x 4095 still fits the u16 pixel sums

RING_SCANS = 8
RING_WORDS = RING_SCANS * N_PIXELS
RING_BYTES = RING_WORDS * 4
RING_SIZE_BITS = 13            # log2(RING_BYTES), DMA write-address ring
DMA_COUNT = 0xFFFFFFFF

PIO0_BASE = 0x50200000
PIO0_FDEBUG = PIO0_BASE + 0x008
PIO0_IRQ = PIO0_BASE + 0x030
PIO0_SM0_CLKDIV = PIO0_BASE + 0x0C8
PIO0_RXF1 = PIO0_BASE + 0x024
DREQ_PIO0_RX1 = 5
FDEBUG_TXSTALL_SM0 = 1 << 24
DMA_CHAN_ABORT = 0x50000444
TIMER_RAWH = 0x40054024
TIMER_RAWL = 0x40054028

PKT_MAGIC = b"\xa5\x5a"
PKT_FRAME = 1
PKT_TEXT = 2
FRAME_HDR_FMT = "<IQIIIBBBBHH"   # 32 bytes, see header comment
FRAME_PAYLOAD = 32 + 2 * N_PIXELS
FRAME_PKT_LEN = 5 + FRAME_PAYLOAD + 4

FLAG_LED_CHANGED = 1
FLAG_RESTART = 2
FLAG_LATE = 4
FLAG_ADC_ERROR = 8

CONFIG_PATH = "/config.json"
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

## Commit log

2026-08-12 kicad files for the rp2040 shield
    [Raspberry pico board.kicad_pcb, Raspberry pico board.kicad_sch]
2026-08-13 Pico Board V2
2026-08-13 V2 Pico Board
2026-08-13 Idek what i am doing here
    [Raspberry pico board.kicad_pcb, Raspberry pico board.kicad_sch]
2026-08-26 Schematic V2.0 finally made it work :)
    [Raspberry pico board.kicad_pcb, Raspberry pico board.kicad_sch]
2026-08-26 C12666MA PCB V2.0
    [Raspberry pico board.kicad_pcb, Raspberry pico board.kicad_sch]
2026-10-05 feat(gui) with revision of the fw
    [Calibration file.csv, Calibration file.xlsx]
2026-10-06 fix(calibration) based on laser line
    [Calibration file.csv, Calibration file.xlsx, green_laser.csv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]
2026-10-06 PAM Meassurement
    [Raspberry pico board Back.kicad_pcb, Raspberry pico board Back.kicad_sch, Raspberry pico board Front.kicad_pcb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]
